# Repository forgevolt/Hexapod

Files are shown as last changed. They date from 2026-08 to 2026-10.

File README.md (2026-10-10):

# Hexapod

A six-legged walking robot built on an ESP32-S3, driving 18 Dynamixel servos with inverse
kinematics at 200 Hz. It walks in three gaits, levels its chassis against uneven ground using
an onboard IMU, and is driven from a separate handheld transmitter over ESP-NOW.

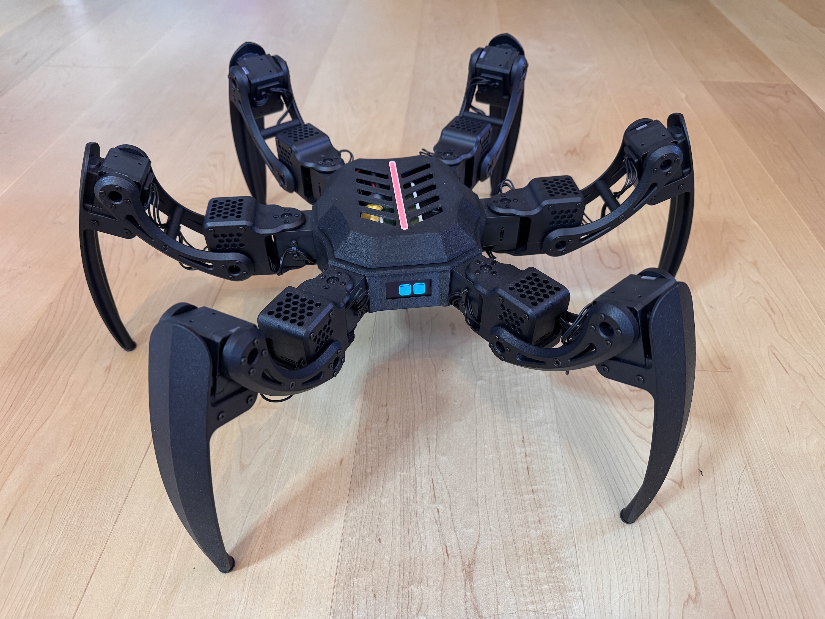
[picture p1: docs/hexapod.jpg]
The hexapod (https://youtu.be/4UdU5Dw7Or8)


▶ **[Watch it walk](https://youtu.be/4UdU5Dw7Or8)** - 14 seconds: leveling on planted feet,
then walking toward the camera.

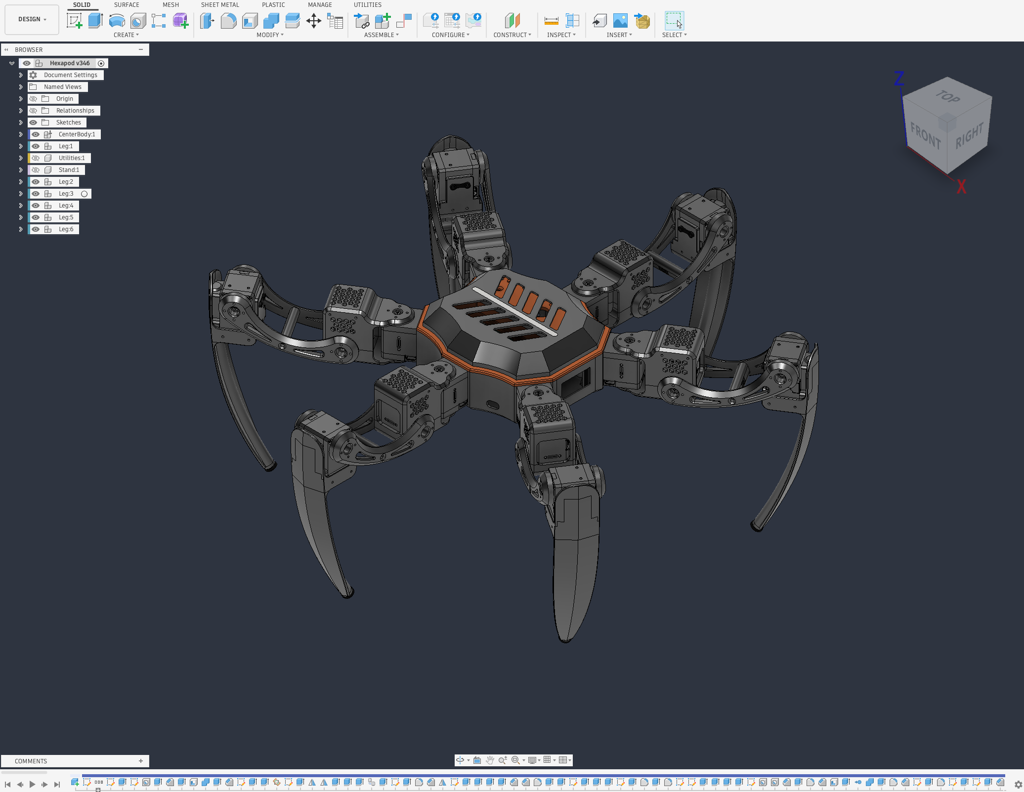
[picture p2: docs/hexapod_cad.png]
The hexapod in Fusion (https://youtu.be/4UdU5Dw7Or8)


## What it does

- **Inverse kinematics per leg.** Each of the six legs solves for coxa, femur and tibia angles
  from a target foot position, with targets clamped to the reachable workspace.
- **Three walking gaits** - tripod, tetrapod and ripple - selected on the fly, with step
  length, step height and ground clearance adjustable from the transmitter while walking.
- **Self-levelling.** `LevelGait` reads the IMU and counters chassis tilt so the body stays
  level on uneven ground while the feet stay planted.
- **Posing.** With the feet planted the chassis can be translated and rotated in roll, pitch
  and yaw, independently of the legs.
- **Animated face.** A 128x64 OLED shows eyes that track the joystick, blink, and change mood
  with the robot's state. It doubles as the fault display when something fails at startup.
- **Sound and lights.** I2S audio for startup, shutdown and error tones, and a 19-LED strip
  whose effect follows the state machine.
- **Power awareness.** Servo torque is released automatically after a period of inactivity,
  and the robot parks itself if the radio link drops.

## Hardware

| Part | What | Notes |
| --- | --- | --- |
| Controller | Custom ESP32-S3 board | 16 MB flash, 8 MB PSRAM; see [`hardware/`](hardware) |
| Servos | 18x Dynamixel XC430-T240BB-T | 3 joints per leg; one half-duplex bus at 3 Mbaud, protocol 2.0 |
| IMU | MPU6050 | I2C, shares the bus with the display |
| Display | SH1106 128x64 OLED | I2C, monochrome |
| LEDs | 19x WS2812B | single data line |
| Audio | I2S DAC / amplifier | 44.1 kHz, 16-bit stereo |
| Transmitter | [Separate handheld unit](https://github.com/forgevolt/Transmitter) | ESP-NOW, WiFi channel 1 |

### Wiring

`software/Hexapod/PinMap.h` is the single source of truth for every GPIO; this table mirrors
it. The schematic is in [`hardware/schematic.pdf`](hardware/schematic.pdf).

| Function | Signal | GPIO |
| --- | --- | --- |
| Dynamixel | RX | 18 |
| Dynamixel | TX | 17 |
| Dynamixel | direction | 16 |
| I2C (display + IMU) | SDA | 8 |
| I2C (display + IMU) | SCL | 9 |
| I2S (audio) | BCLK | 14 |
| I2S (audio) | LRC / word select | 21 |
| I2S (audio) | DOUT | 13 |
| LED strip | data | 11 |
| On/off switch | input | 48 |
| USB sense | input | 10 |

## Repository layout

| | |
|---|---|
| [`software/`](software) | The firmware sketch, plus the bring-up and calibration sketches |
| [`hardware/`](hardware) | PCB: EasyEDA project, Gerbers, schematic, bill of materials |
| [`mechanics/`](mechanics) | Chassis and legs: Fusion source, STLs, dimensioned drawings |
| [`docs/`](docs) | Photographs, the manuals, and the inverse-kinematics write-up |

Each of those has its own README.

### Manuals

| | |
|---|---|
| **[Quick guide](docs/QUICKSTART.md)** | One page, for anyone handed the robot. Controls, what the lights mean, what is normal |
| **[Operating manual](docs/MANUAL.md)** | The full version: servo setup, every control in every mode, timeouts, troubleshooting |

## Getting started

1. Install the required libraries (see **Libraries** below).
2. Open `software/Hexapod/Hexapod.ino` in the Arduino IDE.
3. Select board *ESP32S3 Dev Module* and set the Tools menu as listed under **Board
   settings** below. Four entries differ from the defaults: Flash Size **16 MB**, PSRAM
   **OPI PSRAM** (8 MB), Partition Scheme **Custom** and USB CDC On Boot **Enabled**.
4. Upload.

`software/Hexapod/partitions.csv` sits in the sketch folder, and the ESP32 core picks it up
in preference to the Tools menu: a 6 MB application partition plus a 9.8 MB LittleFS
partition. Nothing in the firmware writes to that filesystem today, but the space is
reserved.

Before the robot will walk, the servos need IDs and a baud rate set, and the joint limits
need to be read off - [`software/DynamixelUtilities/`](software/DynamixelUtilities) exists
for exactly that, and the order to run them in is in that folder's README. One set of limits
covers all six legs (`Hexapod.cpp`), so take values that hold for every leg.

## Building

Built with the **Arduino IDE**, using the **esp32 core 3.3.12** (IDF v5.5.5). It does not
compile against core 2.x.

### Board settings

Board *ESP32S3 Dev Module*, with these Tools-menu settings. The four in bold differ from the
board's defaults.

| Tools menu | Setting |
| --- | --- |
| USB CDC On Boot | **Enabled** |
| CPU Frequency | 240MHz (WiFi) |
| Core Debug Level | None |
| USB DFU On Boot | Disabled |
| Erase All Flash Before Sketch Upload | Disabled |
| Events Run On | Core 1 |
| Flash Mode | QIO 80MHz |
| Flash Size | **16MB (128Mb)** |
| JTAG Adapter | Disabled |
| Arduino Runs On | Core 1 |
| USB Firmware MSC On Boot | Disabled |
| Partition Scheme | **Custom** |
| PSRAM | **OPI PSRAM** |
| Upload Mode | UART0 / Hardware CDC |
| Upload Speed | 921600 |
| USB Mode | Hardware CDC and JTAG |
| Zigbee Mode | Disabled |

For `arduino-cli`, the same settings as an FQBN:

```
esp32:esp32:esp32s3:CDCOnBoot=cdc,FlashSize=16M,PartitionScheme=custom,PSRAM=opi
```

### Libraries

Install through the Arduino library manager. These are the versions it is built and tested
against:

| Library | Version | Note |
| --- | --- | --- |
| FastLED | 3.10.6 | |
| Dynamixel2Arduino | 0.8.2 | |
| MPU6050_light | 1.2.1 | by rfetick - several MPU6050 libraries exist, this is the one used here |
| U8g2 | 2.36.19 | |
| Streaming | 6.3.0 | |
| [SoundEngine](https://github.com/forgevolt/SoundEngine) | 1.1.1 | I2S mixing and the compiled-in clips |
| [ESPNowUtilities](https://github.com/forgevolt/ESPNowUtilities) | 1.0.1 | the ESP-NOW transport `RCProtocol.h` is built on |
| [VectorUtilities](https://github.com/forgevolt/VectorUtilities) | 1.0.0 | `Vector2`/`Vector3`, rotations and the motion curves of the gaits |

The last three are written for this project and its transmitter. All three are in the Arduino
Library Manager, so nothing here needs installing by hand.

`software/Hexapod/RCProtocol.h` defines the wire format, and it is **a copy**: the master
lives in the transmitter repository, because the format follows the transmitter's hardware.
Arduino cannot include across sketch folders, hence the duplication. `cAppProtocolVersion`
is the guard - both ends check it on every frame, so a copy that has fallen behind shows up
as a logged mismatch at pairing rather than as silently misread data.

### Compiler warnings

`software/Hexapod/build_opt.h` switches on more warnings than the core does:

```
-Wall
-Wextra
-Wdouble-promotion
-Wsign-compare
```

`-Wdouble-promotion` matters on the ESP32-S3, which has no hardware double: it catches float
maths that silently turns into slow double maths. `-Wsign-compare` has to be listed by name:
the core's `cpp_flags` passes `-Wno-sign-compare`, and a specific `-Wno-` beats a later
umbrella flag such as `-Wall`. Arduino expands `build_opt.h` after `cpp_flags`, which is why
overriding it there works. Delete the file and these warnings silently disappear from the
build.

The firmware builds without a warning from its own sources. The flags apply to the core and
the libraries as well, so a clean build still lists several hundred warnings from those,
most of them from FastLED.

The IDE setting *Compiler warnings: None* (File → Preferences) passes `-w`, which hides every
warning, including the ones `build_opt.h` asks for. Use *Default* or higher. The IDE's output
panel also drops the start of a long log, so for a full warning check compile with the
`arduino-cli` that ships with the IDE and keep the log in a file outside the repository
(macOS paths):

```bash
CLI="/Applications/Arduino IDE.app/Contents/Resources/app/lib/backend/resources/arduino-cli"
cd software
"$CLI" compile --clean --warnings all \
  --fqbn "esp32:esp32:esp32s3:CDCOnBoot=cdc,FlashSize=16M,PartitionScheme=custom,PSRAM=opi" \
  Hexapod 2>&1 | tee ~/hexapod-build.log
```

`--warnings all` matters: without it `arduino-cli` uses `none`, which passes `-w` just like
the IDE setting. The flags themselves come from `build_opt.h`.

## How it runs

Four FreeRTOS tasks, deliberately split across cores so that nothing can delay servo timing:

| Task | Priority | Core | Rate | Does |
| --- | --- | --- | --- | --- |
| `schedulerTask` | 8 | 1 | 200 Hz | the control loop: gait step, IK, servo write |
| `linkTask` | 3 | 0 | - | ESP-NOW send and receive |
| `peripheralsTask` | 2 | 1 | 50 Hz | IMU read, display and LED updates |
| `fillBuffer` | 1 | 1 | - | mixes and queues the next audio chunk (owned by SoundEngine) |

The display and the IMU share one I2C bus, owned exclusively by `peripheralsTask` - it is the
only task that may touch either. The display runs the bus at 800 kHz and U8g2 does not
restore the previous clock, so the task pulls it back to 400 kHz before every IMU read,
since the MPU6050 is not rated above that.

## Acknowledgements

**Zenta (Kåre Halvorsen)** - the GOAT of hexapods. Years of his work set the bar for what a
legged robot should look like when it moves.
[GitHub](https://github.com/Zenta) · [YouTube](https://www.youtube.com/@ZentaRobotics)

**Design inspiration**

- **Matt Bunting** - [[1]](https://youtu.be/xLxrb_P6N7o) [[2]](https://youtu.be/CVHd2_NUgIs)
- **naoa nya** - [kumokun](https://github.com/naoanya/kumokun/) · [video](https://youtu.be/WcUX7GgypG0)

**Inverse kinematics**

- **Jakob Leander**, *Master Inverse Kinematics for Arduino Robots - Easy Math, Full Code,
  Real Results*. [Video](https://youtu.be/WAsMAeKDc4U) ·
  [Code](https://github.com/JakobLeander/hexapod). The derivation in `Leg.cpp` follows this
  tutorial; [`docs/`](docs) works it through for this geometry.

**Dennis Hoelscher** - [RoboEyes](https://github.com/FluxGarage/RoboEyes), the idea behind
the animated face. `StatusDisplay` was written from a description of the behaviour rather
than from that source; the acknowledgement is in its header.

## Licence

MIT - see [LICENSE](LICENSE). Third-party library licences are listed in
[THIRD_PARTY.md](THIRD_PARTY.md).

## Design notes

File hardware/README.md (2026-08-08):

# PCB

The custom ESP32-S3 controller board: everything needed to have it made, and to change it.

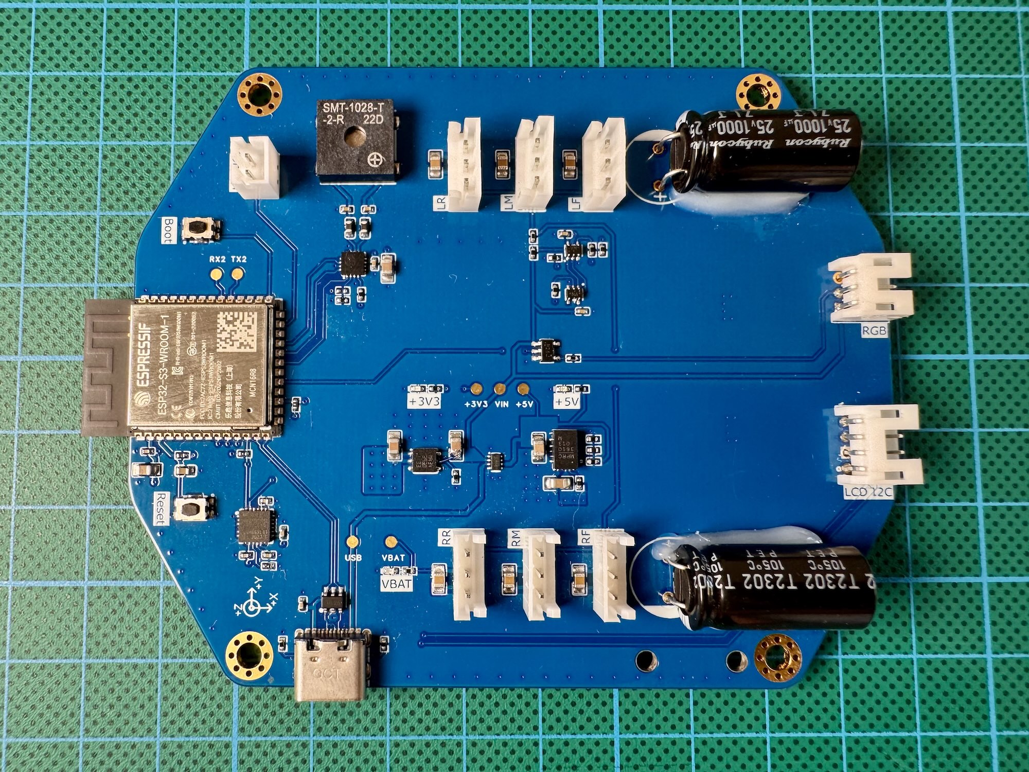
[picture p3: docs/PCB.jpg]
PCB


| Test harness 1 | Test harness 2 |
|---|---|
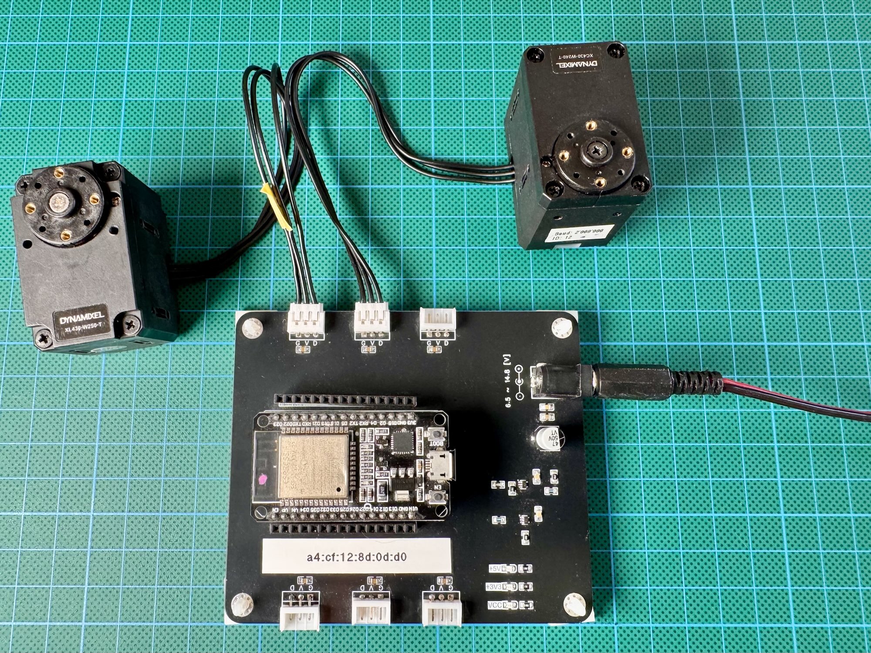
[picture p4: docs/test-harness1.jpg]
Test 1
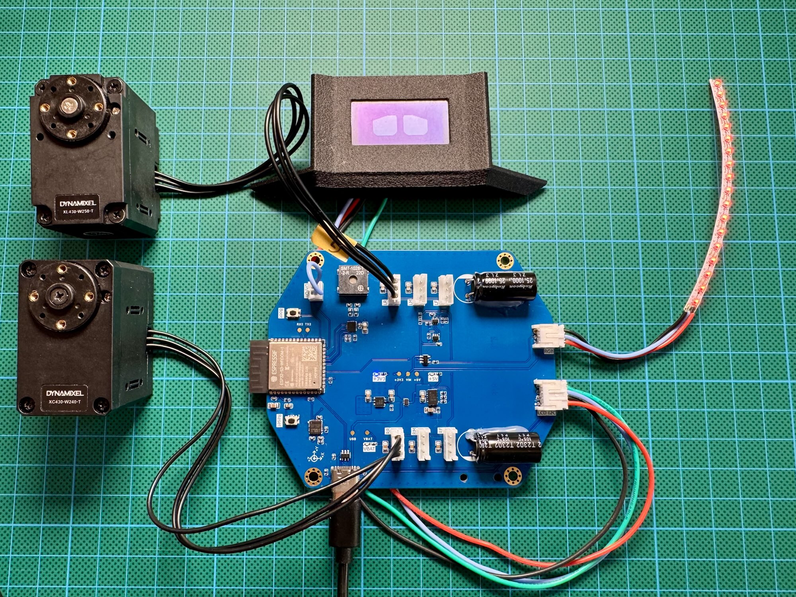
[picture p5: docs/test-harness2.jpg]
Test 2
|  |  |

| Path | Contents |
|---|---|
| `easyeda/ProPrj_Hexapod_2026-08-06.epro2` | The editable EasyEDA Pro project - schematic and layout |
| `gerber/Gerber_HexapodPCB_R2_2026-08-06.zip` | Fabrication files for revision R2, zipped as a fab expects them |
| `schematic.pdf` | The schematic as a document, readable without EasyEDA |
| `bom.csv` | Bill of materials, with LCSC part numbers |
| `MPM3610Calculator.xlsx` | Working sheet for the MPM3610 buck regulator - feedback divider and inductor choice |

The board here is **revision R2**. The Gerber archive and the EasyEDA project carry the
revision and the export date in their filenames, so a later revision can sit beside this one
rather than silently replacing it.

## Ordering a board

Upload `gerber/Gerber_HexapodPCB_R2_2026-08-06.zip` as it is - a standard Gerber and drill
set. The BOM lists LCSC part numbers, which suits JLCPCB assembly, but nothing in the design
depends on a particular fab.

If you revise the layout, tag this repository when you order from it. A year later, "which
files made the board in my hand" then has an answer the tree alone cannot give.

## The BOM

`bom.csv` is exported from EasyEDA and is UTF-8. Some manufacturer names carry their Chinese
form alongside the Latin one - `SAMSUNG(三星)`, `KELIKING(凯丽金)` - which is how LCSC lists
them. If those render as mojibake, the reader is guessing the encoding rather than the file
being wrong.

## What is on the board

From the BOM, the parts worth naming:

| Part | Function |
|---|---|
| MPM3610GQV-Z | Step-down module, the +5V rail |
| LD39200PUR | 2 A LDO, the +3V3 rail |
| SMCJ15A | TVS on the battery input |
| 74LVC1G125 / 74LVC1G126 | The direction buffers that make the Dynamixel bus half-duplex |
| MAX98357AETE+T | I2S class-D amplifier |
| MPU-6050 | IMU |

`MPM3610Calculator.xlsx` is the working sheet behind the buck regulator's component values.
The schematic is the authority for what was actually built.

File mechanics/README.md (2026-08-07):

# Mechanics

The chassis and legs: Fusion source, print-ready meshes, and the dimensioned drawings.

| Path | Contents |
|---|---|
| `cad/Hexapod.f3z` | The Fusion source, as an archive containing the whole assembly |
| `stl/` | Print-ready meshes, 18 parts |
| `dimensions-top.png`, `dimensions-side.png` | Overall dimensions |

## Leg naming

The code names each leg's three links after an insect's, and the STLs follow:

| Link | Joint it rotates about | Moves |
|---|---|---|
| **Coxa** | vertical, at the body | the leg left and right, swinging it around the chassis |
| **Femur** | horizontal, at the coxa | the leg up and down |
| **Tibia** | horizontal, at the femur's far end | the foot in and out, setting how far the leg reaches |

`Leg.cpp` solves for the three angles in that order, and `PresentPosition/` prints them in
it too.

## The parts

| Group | Parts | Per robot |
|---|---|---|
| Centre body | `CenterBody-Main`, `-TopPlate`, `-CoverWithDiffusor`, `-CoverLedHolder`, `-ConnectorTopPlate`, `-ConnectorCover`, `-DisplayHolderLeft`, `-DisplayHolderRight` | 1 each |
| Cable entries | `CenterBody-Grommet-1Cable`, `-Grommet-2Cable`, `Femur-Groomet`, `CoxaTibia-CableFixture` | as needed |
| Leg | `Coxa-Upper`, `Coxa-Lower`, `Femur-Bracket1`, `Femur-Bracket2`, `Femur-ConnectingBracket`, `Tibia` | 6 each |

Six legs means the leg parts print six times over. Mirroring is not required - the legs are
identical and their difference is in the firmware's per-leg mounting angles.

## Opening the CAD

`Hexapod.f3z` is a Fusion archive rather than a single `.f3d` part - open it with
*File → Open* in Fusion, which unpacks the design and its components.

There is no STEP export here. If you want to modify the chassis without a Fusion licence, a
STEP export is the thing to ask for; the STLs are fine for printing but carry no editable
geometry.

## Printing

No slicer projects are included, so use your own profile. The parts that carry load are the
coxa and femur brackets and the centre body's top plate - a leg's own weight plus the
servo's stall torque goes through them, so treat infill and wall count there as structural
rather than cosmetic. The cover with the diffusor is the exception in the other direction:
it is meant to pass light from the LED strip.

## Servo and bracket geometry

The printed parts are dimensioned around two ROBOTIS components:

| Part | Role |
|---|---|
| **XC430-T240BB-T** | the servo, three per leg |
| **HN11-I101** | the idler bearing set for DYNAMIXEL XL 430 series |

Their drawings and STEP models are not reproduced here - they are ROBOTIS's documents, and
the current versions are on the
[ROBOTIS e-Manual](https://docs.robotis.com/docs/dxl/model_reference/x_series/xc_series/xc430-t240bb). Download them
from there if you need to check a fit or modify a bracket.

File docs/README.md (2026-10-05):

# Documentation

| Path | Contents |
|---|---|
| [`QUICKSTART.md`](QUICKSTART.md) | Quick guide - one page, for anyone handed the robot |
| [`MANUAL.md`](MANUAL.md) | Operating manual - servo setup, every control, troubleshooting |
| `state-machine-detail.md` | The state machine with guards, gaits and constants from `Hexapod.cpp` |
| `state-machine.svg`, `state-machine-detail.svg` | The same two diagrams as SVG, if you prefer them to the inline Mermaid |
| `transmitter-controls.jpg` | The annotated transmitter photo the quick guide shows |
| `hexapod.jpg` | The photograph the top-level README shows |
| `PCB.jpg` | The assembled controller board, shown in `hardware/README.md` |
| `test-harness1.jpg`, `test-harness2.jpg` | The bring-up harness, shown in `hardware/README.md` |
| `Hexapod-IKMath.pdf` | The inverse-kinematics derivation for this geometry |

## `Hexapod-IKMath.pdf`

The maths behind `software/Hexapod/Leg.cpp`, worked through for this robot's link lengths
and mounting angles: from a target foot position in body coordinates, to coxa, femur and
tibia angles.

`Leg.cpp` follows the approach in Jakob Leander's
[tutorial](https://youtu.be/WAsMAeKDc4U); this document carries it through for the
dimensions in `mechanics/`, which is what makes the constants in the code readable rather
than magic.

`software/IKMath/` is the runnable companion - the same `Leg` code, with no
robot attached.

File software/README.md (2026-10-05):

# Software

Four sketch trees. Only the first one is the robot; the rest are bring-up tools that exist
because an 18-servo machine is painful to debug all at once.

| Path | What |
|---|---|
| `Hexapod/` | The firmware. This is the one you flash |
| `DynamixelUtilities/` | Servo setup and measurement, run before first assembly |
| `IKMath/` | The inverse kinematics on its own, no robot required |
| `HWTests/` | Per-peripheral smoke tests |

## `Hexapod/` - the firmware

| Files | Responsibility |
| --- | --- |
| `Hexapod.ino`, `Hexapod.*` | state machine, task setup, telemetry, and the top-level `step()` |
| `Leg.*` | per-leg inverse and forward kinematics (the vector maths come from VectorUtilities) |
| `GaitEngine.*`, `Gaits.*` | gait scheduling, and the park, stand, pose, level and walking gaits |
| `ServoBus.*` | the Dynamixel bus: sync read/write, joint limits, torque |
| `Receiver.*`, `RCProtocol.h` | the ESP-NOW link, control data in and telemetry out |
| `StatusDisplay.*` | the eyes and the fault display |
| `IndicatorLeds.*` | the LED strip effects |
| `PinMap.h` | every GPIO in the project |
| `build_opt.h` | extra compiler warnings: `-Wall -Wextra -Wdouble-promotion -Wsign-compare` |
| `partitions.csv` | 6 MB app + 9.8 MB LittleFS; overrides the Tools menu |

The state machine in `Hexapod.cpp` - every state, guard, gait and timeout - is drawn in
[`docs/state-machine-detail.md`](../docs/state-machine-detail.md).

Audio and radio transport are not here - they are the `SoundEngine` and `ESPNowUtilities`
libraries, installed through the Library Manager. `RCProtocol.h` is a copy of the
transmitter's master; see the note in the top-level README.

## `DynamixelUtilities/` - servo setup

Each sketch talks to the servo bus and nothing else. Out of the box a Dynamixel is ID 1 at
57600 baud, so a new leg has to be set up one servo at a time, with only that servo on the
bus.

Run them roughly in this order when building a leg:

| Sketch | What it does |
|---|---|
| `SetBaudRate/` | Scans the bus, detects the current baud rate, sets it to the target. One servo at a time |
| `SetID/` | Same scan, then assigns the servo its ID. One servo at a time |
| `DefaultPosition/` | Drives every servo on the bus to 2048, the mechanical centre. Assemble the joint in this position |
| `PresentPosition/` | Prints the live positions of one leg's three servos, and the min/max seen. This is how the joint limits in `ServoBus` were measured |
| `Position1/`, `Position2/` | Two approaches to smooth point-to-point motion: way points with a blend threshold, versus streaming goal positions at 100-200 Hz. The firmware uses the second |

**Set the baud rate and the ID with one servo connected.** Both sketches scan and write to
whatever they find, so a whole bus will end up with the same ID.

## `IKMath/` - kinematics without the robot

`IKMath.ino` runs the same `Leg` as the firmware, decoupled from the
state machine, the radio and the gaits. It made the maths debuggable in isolation, and it is
the sketch to reach for when changing the kinematics. `Leg.*` and `ServoBus.*` here
are copies of the firmware's, for the same Arduino include reason as `RCProtocol.h` - keep
them in step.

## `HWTests/`

| Sketch | Needs | Checks |
|---|---|---|
| `StatusDisplayTest/` | an SH1106 OLED on I2C | Walks the whole `StatusDisplay` API - eyes, moods, blinking, the fault face - holding each step long enough to watch and logging what it is showing |
| `tone/` | the I2S amplifier | Plays C5-E5-G5. Enough to tell wiring from software |

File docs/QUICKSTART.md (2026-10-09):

# Quick guide

How to drive the hexapod. No prior knowledge needed.

## Switch it on

Turn on the transmitter, then the robot. The robot plays a sound, folds its legs into a
resting crouch, and pulses red while it looks for the transmitter. That takes a few seconds.

When the eyes open and the transmitter shows the robot's name, it is ready.

**Press the left button** to make it stand up.

## The controls

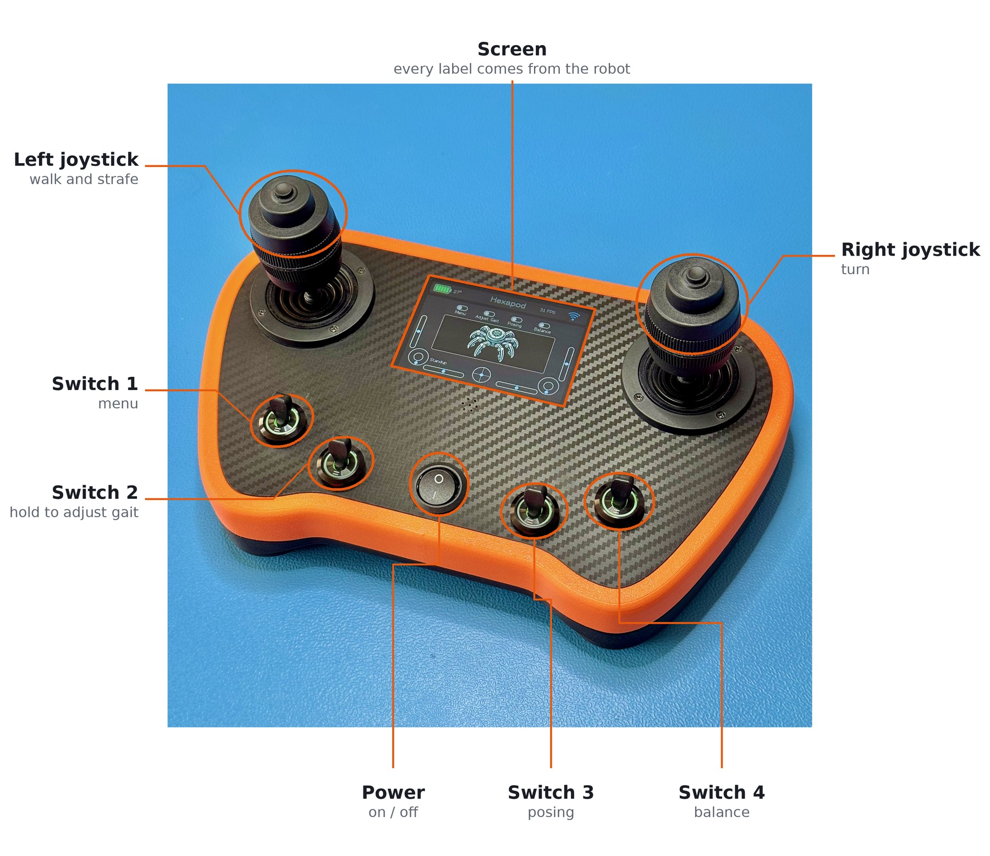
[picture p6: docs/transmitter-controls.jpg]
The transmitter's controls


*The two-joystick transmitter. The one-joystick version has the same switches, and you turn
by twisting the single stick.*

The transmitter labels every switch and button, and those labels change with what the robot
can do right now. A blank label means that control does nothing at the moment.

| Control | Does |
|---|---|
| **Left button** | Stand up, or lie back down |
| **Right button** | Change the walking style. While it lies down: set what counts as level (see below) |
| **Switch 2** — *Adjust Gait* | Hold to change how it walks (see below) |
| **Switch 3** — *Posing* | Feet stay put, the body moves |
| **Switch 4** — *Balance* | The robot keeps itself level |

## Walking

Once it is standing, **just push the left stick**. There is no separate "go" command.

- **Forward and back**, **left and right**: the left stick
- **Turning**: the right stick sideways, or — if your transmitter has only one stick —
  twist that stick

**How far you push decides how fast it walks.** Push gently for a slow walk. Let go and it
finishes its step and stops.

The **right button** cycles through three walking styles while it walks:

- **Tripod** — quick, moves three legs at once
- **Tetrapod** — a good all-rounder
- **Ripple** — slow and steady, one leg at a time, best on rough ground

## Changing how it walks

**Hold Switch 2** and the right stick stops steering and starts adjusting instead:

- **Sideways** — how big a stride it takes
- **Up and down** — how high it stands
- **Twist** — how high it picks its feet up

The values show on the transmitter as you change them, and they stay where you leave them.
It walks straight while you are holding Switch 2 — you cannot steer and adjust at once.

Without Switch 2 held, pushing the right stick up and down still raises and lowers the body,
but only for as long as you hold it. Useful for ducking under something.

## Posing and balancing

**Switch 3 — Posing.** The feet stay planted and the body moves on top of them. The left
stick shifts it around and up and down; the right stick tilts and turns it. Movements are
deliberately soft and slow.

*A trick:* with Switch 3 and Switch 4 both on, tilt the **transmitter itself** and the robot's
body copies you.

**Switch 4 — Balance.** The robot feels which way is down and keeps its body level, even if
the ground is not. Stand it on a slope and it will straighten up. It does not walk while
doing this.

If it holds itself a little crooked on flat ground, let it lie down on a level floor and press
the **right button** (*Level IMU*). A short signal confirms it, and it remembers this from then
on. This needs the two-joystick transmitter.

Turn the switch off and it goes back to standing normally.

## What it is telling you

**The lights:**

| | |
|---|---|
| Pulsing red | Standing by, not moving |
| Pulsing orange | Posing or balancing |
| Running along the body | Walking — the direction follows where it is going |

**The eyes:** tired while starting up, curious while standing, narrowed and focused while
walking, happy while posing or balancing. They follow the stick as you steer.

## Things that are normal

**It goes limp after a while.** If it sits parked and unused for a minute, it relaxes its
joints so the motors do not overheat. Any command wakes it up again.

**It lies down on its own.** Left standing with nothing to do for half a minute, it parks
itself.

**It parks when you switch the transmitter off** — or when you walk out of range. It stands
by and re-connects on its own as soon as the transmitter is back.

**Buttons go blank for a few seconds.** It is standing up or lying down, and will not take
new commands until it has finished.

## If something is wrong

The robot shows faults on its own screen, as a crossed-eye face with a line of text, along
with a warning sound.

| It says | Meaning |
|---|---|
| **SERVO INIT FAILED** | The legs did not respond at startup. Switch it off and check that servo power is connected. **Do not ask it to stand.** |
| **ABNORMAL RESET** | The last run ended badly rather than being switched off. It clears itself after twenty seconds. If it says *brownout*, the battery is probably low |
| **IMU INIT FAILED** | The balance sensor did not respond at startup. Everything else works, but Balance will not level the robot. This one comes without the warning sound |
| **SERVO READ FAILED** | The robot could not tell where its legs are. If its legs were limp, it leaves them limp instead of moving them blindly and tries again with the next park or stand-up; if it was standing, a leg may have lost its connection. If it keeps happening, switch off and check the servo cables. This one comes without the warning sound |
| **BATTERY LOW** | The battery is nearly empty. The message and the sound come back every minute until you park the robot and change or charge the battery |

**Nothing responds and it keeps pulsing red.** It has not found the transmitter. Check the
transmitter is on and paired.

**It walks but will not turn.** Switch 2 is on — steering is off while you are adjusting.

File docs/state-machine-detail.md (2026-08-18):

# State machine — firmware view

Every state, guard, gait and timeout in `software/Hexapod/Hexapod.cpp`. For the same machine
in operating terms, see [the manual](MANUAL.md#the-five-things-it-does).

The Mermaid below is the source. [`state-machine-detail.svg`](state-machine-detail.svg) is the
same diagram exported for printing - **if you change one, change the other.**

```mermaid
flowchart LR
    Off["eOff"] -->|"isSwitchOn()<br>play(startupClip)<br>ParkGait 3000 ms"| Init["eInitializing"]
    Init -->|"!isSwitchOn()<br>setTorqueOff()<br>play(shutdownClip)"| Off
    Init -->|"isLinkHealthy()<br>re-park if !isAllTorqueOn()"| Ready["eReady"]
    Init -->|"60 s: setTorqueOff()"| Init
    Ready -->|"60 s: setTorqueOff()"| Ready
    Ready -->|"joyL &amp;&amp; canChangeGait()<br>StandUpGait 3000 ms"| Standing["eStanding"]
    Standing -->|"30 s idle<br>ParkGait 3000 ms"| Ready
    Standing -->|"any axis != 0 ||<br>joyR || switch2<br>walkingGaits[i]"| Walking["eWalking"]
    Walking -->|"15 s idle &amp;&amp; !switch2<br>StandUpGait 1000 ms"| Standing
    Walking -->|"joyR: ++gait index"| Walking
    Standing -->|"switch3<br>PosingGait"| Posing["ePosing"]
    Posing -->|"!switch3<br>StandUpGait 1000 ms"| Standing
    Standing -->|"switch4<br>LevelGait"| Leveled["eStandingLeveled"]
    Leveled -->|"!switch4<br>StandUpGait 1000 ms"| Standing
    Walking -.->|"switch3 &amp;&amp; !switch2<br>PosingGait"| Posing
    Walking -.->|"switch4 &amp;&amp; !switch2<br>LevelGait"| Leveled
    Leveled -.->|"switch3<br>PosingGait"| Posing

    N["<b>Common to the four active states</b><br>eStanding, eWalking, ePosing, eStandingLeveled<br>&nbsp;<br>joyL → ParkGait 3000 ms → eReady<br>!isLinkHealthy() || !isSwitchOn()<br>&nbsp;&nbsp;→ handleConnectionLoss(true) → eInitializing<br>&nbsp;&nbsp;the same from eReady, but with (false):<br>&nbsp;&nbsp;no gait is running there to interrupt"]
    Off ~~~ N

    linkStyle 14,15,16 stroke:#3A56A8,color:#3A56A8
    classDef s_off  fill:#E7E9EC,stroke:#3A4048,stroke-width:2px,color:#1A1E24
    classDef s_init fill:#FDE7D6,stroke:#E8590C,stroke-width:2px,color:#1A1E24
    classDef s_stnd fill:#FFF3BF,stroke:#B58B00,stroke-width:2px,color:#1A1E24
    classDef s_walk fill:#D9F2E0,stroke:#2B8A3E,stroke-width:2px,color:#1A1E24
    classDef s_mode fill:#E3E9FB,stroke:#3A56A8,stroke-width:2px,color:#1A1E24
    classDef s_note fill:#FFFDF3,stroke:#B58B00,stroke-width:1.5px,color:#1A1E24
    class Off s_off
    class Init,Ready s_init
    class Standing s_stnd
    class Walking s_walk
    class Posing,Leveled s_mode
    class N s_note
```

## Guards

`isLinkHealthy()` = `isPaired()` **and** `timeSinceLastControlData()` ≤ 250 ms. The two are
deliberately independent: the first is the transport layer's opinion, the second is the
control loop's own, and it catches a stalled WiFi task that would never clear the peer.

`canChangeGait()` gates every handler **except** `stepWalking()`. A state change from walking
therefore takes effect immediately while the gait switch is deferred to the end of the cycle;
the destination handler's own entry gate covers the gap.

## Constants

All in `Hexapod.cpp`.

| | |
|---|---|
| `cParkDurationMs` | 3000 |
| `cStandUpFromParkedMs` | 3000 |
| `cStandUpDeployedMs` | 1000 |
| `cIdleTimeout` | 15000 |
| `cWaitTimeUntilTorqueOff` | 60000 |
| `cControlDataTimeoutMs` | 250 |

## Regenerating the SVGs

Both SVGs are built with graphviz from the sources in [`diagrams/`](diagrams), then composed
so the note sits below the graph - `dot` lays nodes out by rank and cannot place a note
underneath a left-to-right graph on its own.

```
cd docs/diagrams
./build.sh          # needs graphviz and python3
```

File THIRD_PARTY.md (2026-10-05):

# Third-party licences

This firmware is MIT licensed (see LICENSE). It builds against the libraries below. None of
them are redistributed here - each is installed through the Arduino library manager and
keeps its own licence.

| Library | Licence | Used for |
| --- | --- | --- |
| FastLED | MIT | the indicator LED strip |
| MPU6050_light | MIT | the onboard IMU |
| Dynamixel2Arduino | Apache-2.0 | the servo bus |
| U8g2 | BSD 2-clause (code)  | the OLED display |
| Streaming | LGPL-2.1-or-later | the `Serial <<` logging |
| SoundEngine | MIT | I2S mixing and playback |
| ESPNowUtilities | MIT | the ESP-NOW link to the transmitter |
| VectorUtilities | MIT (raymath: zlib)  | vectors, rotations, motion curves |

The last three are written for this project and published separately, under the same MIT
licence as this repository:
[SoundEngine](https://github.com/forgevolt/SoundEngine),
[ESPNowUtilities](https://github.com/forgevolt/ESPNowUtilities) and
[VectorUtilities](https://github.com/forgevolt/VectorUtilities). VectorUtilities' vector code is
derived from raymath, part of [raylib](https://github.com/raysan5/raylib) (zlib licence); the
library carries raylib's licence notice.

## Streaming

`Streaming.h` by Mikal Hart is used for logging throughout the firmware. The LGPL does not
affect the licence of this project, but it asks that anyone who receives a binary can relink
it against a modified version of the library. Complete source is published here and no
pre-built binaries are distributed, so a recipient can modify Streaming and rebuild.

## U8g2 fonts

U8g2's code is BSD 2-clause, but its fonts are licensed separately. StatusDisplay renders
fault text with `u8g2_font_helvR08_tr`, derived from HELVR08.BDF:

    Copyright 1984-1989, 1994 Adobe Systems Incorporated.
    Copyright 1988, 1994 Digital Equipment Corporation.

    Permission to use, copy, modify, distribute and sell this software and its
    documentation for any purpose and without fee is hereby granted, provided that
    the above copyright notices appear in all copies. Adobe Systems and Digital
    Equipment Corporation make no representations about the suitability of this
    software for any purpose. It is provided "as is" without express or implied
    warranty.

The same notice is reproduced at the top of `StatusDisplay.h`.

## StatusDisplay

Written for this project, implemented from a description of the behaviour rather than from
the source of FluxGarage RoboEyes, which inspired it. The acknowledgement is in the header.

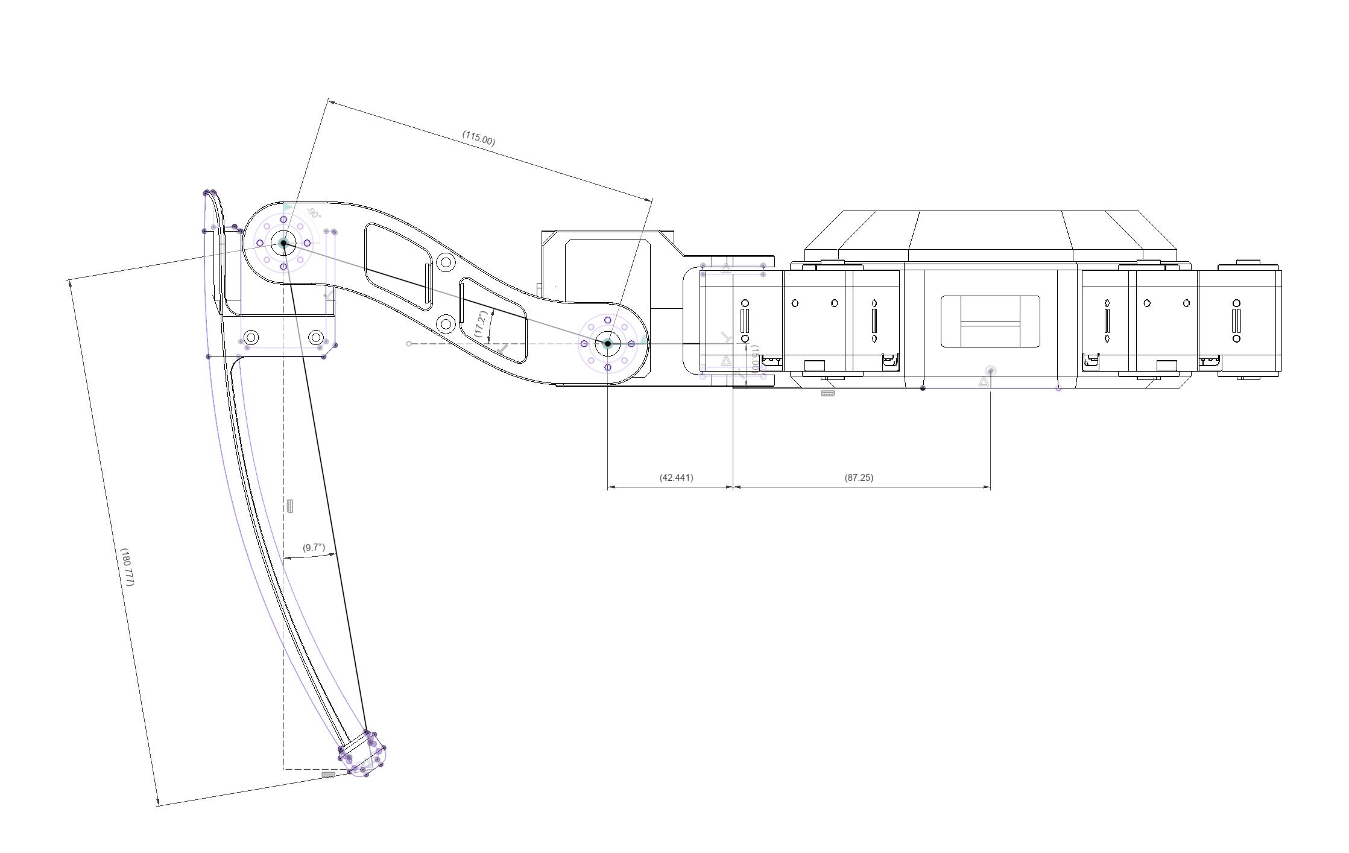
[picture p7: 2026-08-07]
mechanics/dimensions-side.png

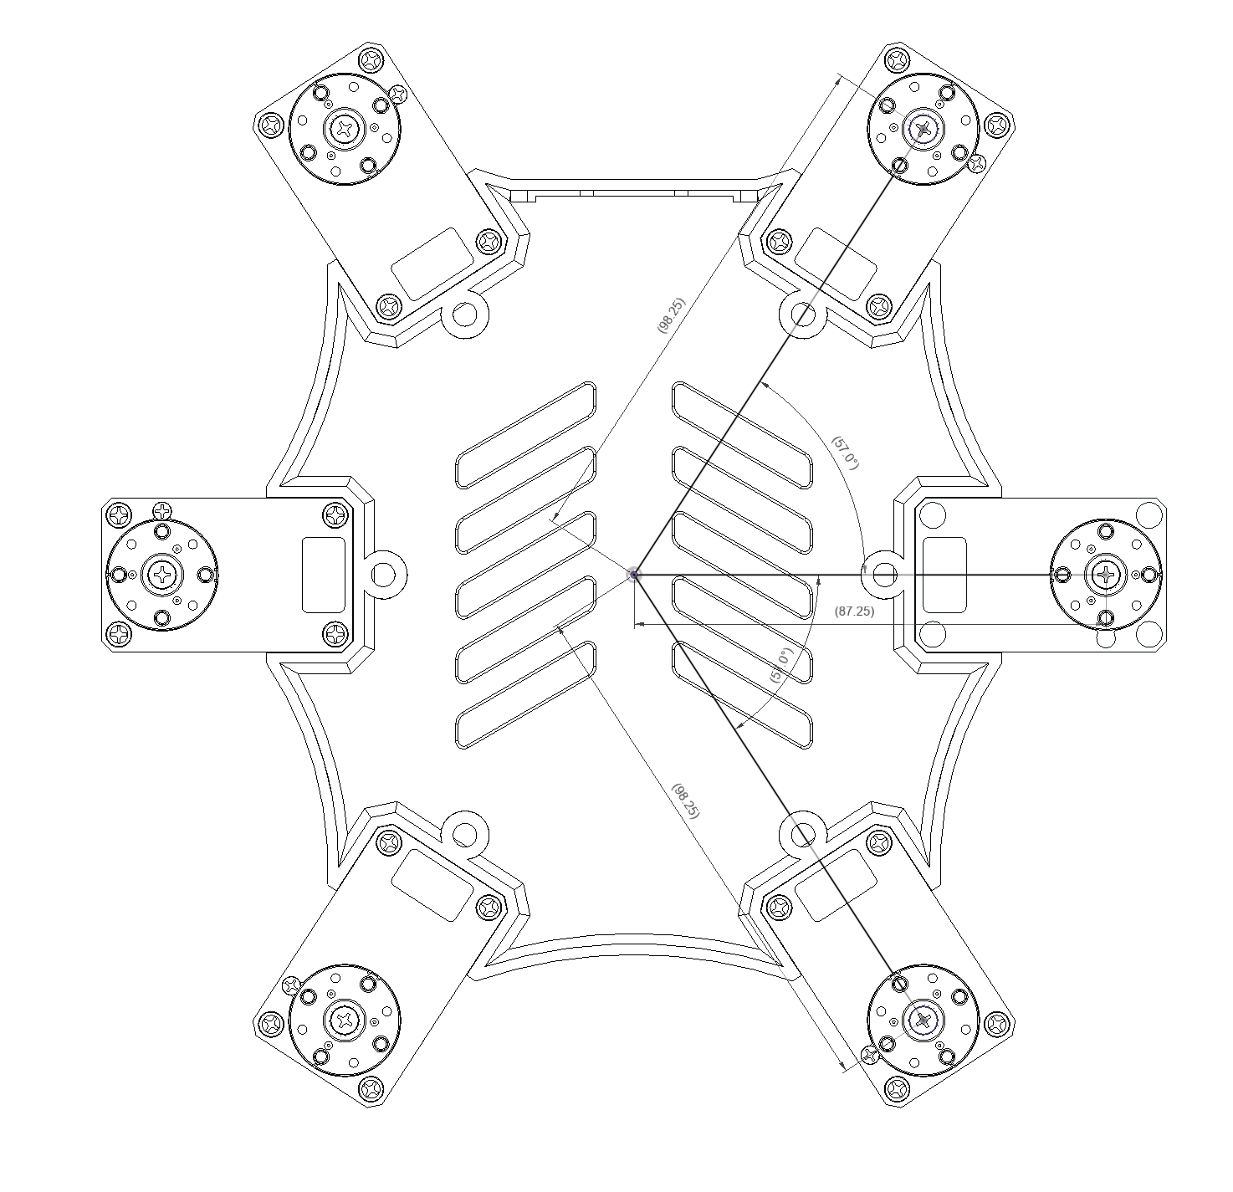
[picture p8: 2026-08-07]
mechanics/dimensions-top.png

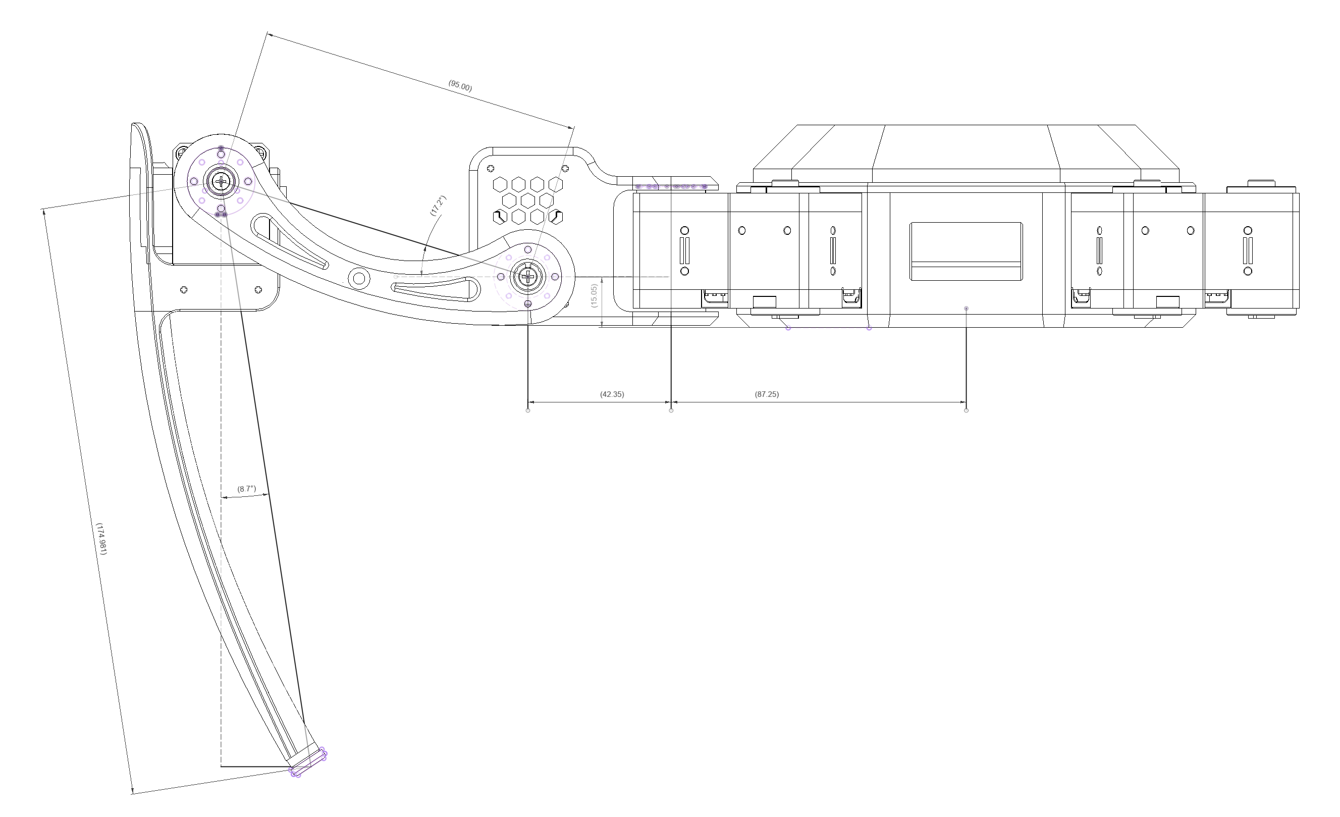
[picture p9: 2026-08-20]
docs/side_distances_for_IK.png

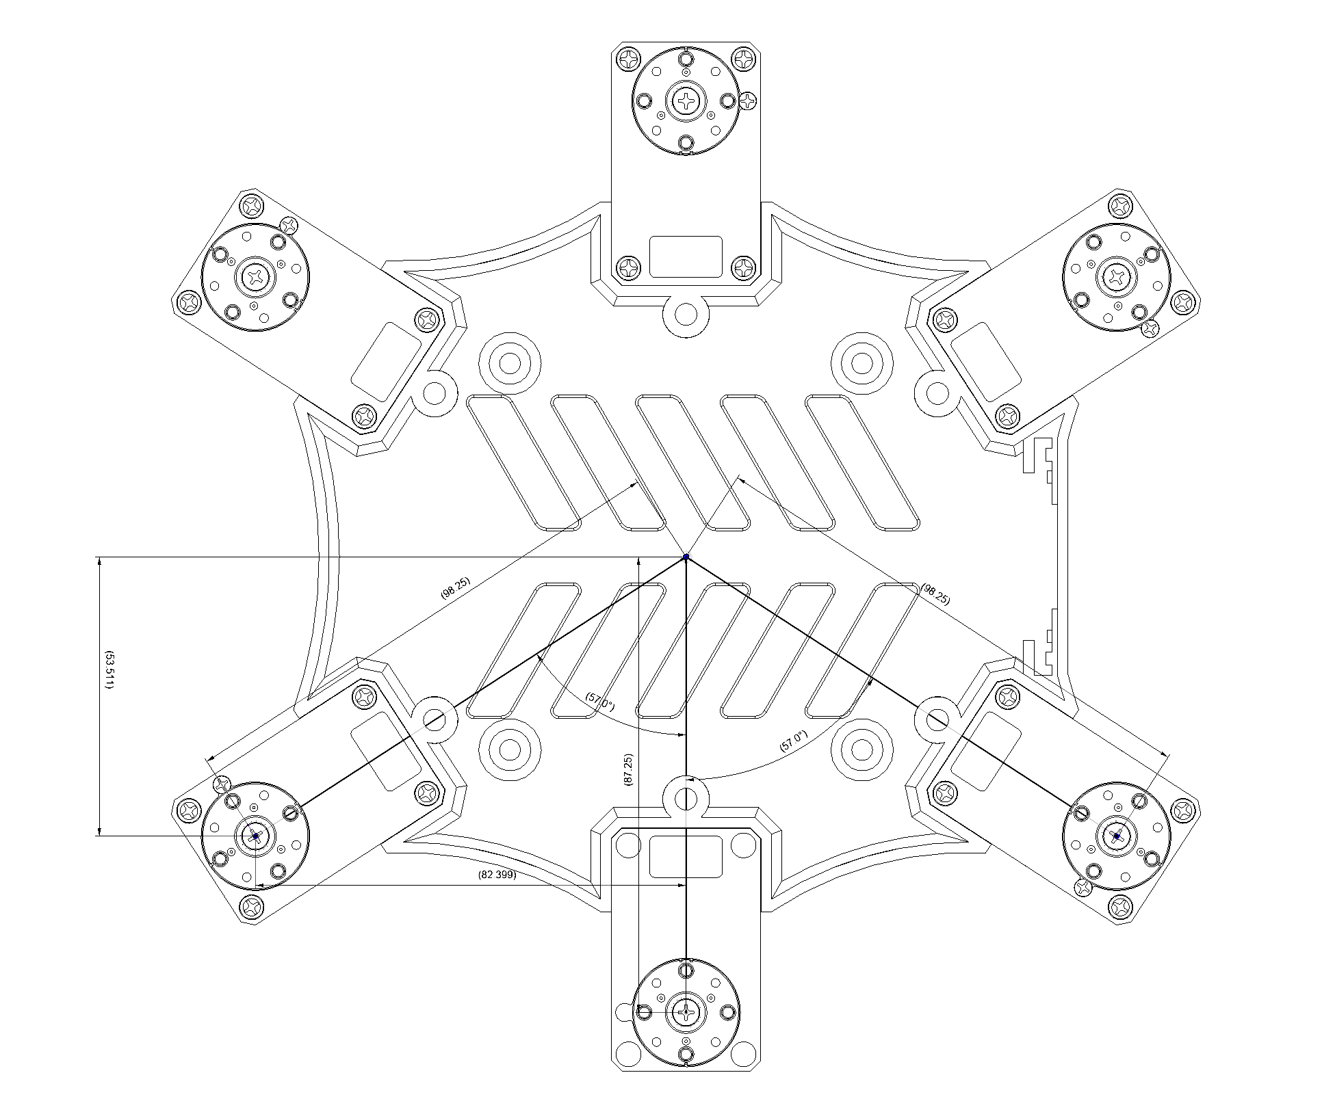
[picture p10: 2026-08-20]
docs/top_distances_for_IK.png

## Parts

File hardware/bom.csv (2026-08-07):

No. | Quantity | Comment | Designator | Footprint | Value | Manufacturer Part | Manufacturer | Supplier Part | Supplier
1 | 1 | BatteryPads | B400 | BatteryPads
2 | 7 | 100nF | C200,C302,C501,C601,C602,C802,C805 | C0402_IPC | 100nF | CL05B104KO5NNNC | SAMSUNG(三星) | C1525 | LCSC
3 | 1 | 1uF | C300 | C0603 | 1uF | CL10B105KP8NNNC | SAMSUNG(三星) | C95843 | LCSC
4 | 2 | 22uF | C301,C404 | C0805 | 22uF | CL21A226MAQNNNE | SAMSUNG(三星) | C45783 | LCSC
5 | 2 | 1000uF | C400,C401 | CAP-TH_BD10.0-P5.00-D1.0-FD | 1000uF | 25YXJ1000M10X20 | rubycon(红宝石) | C88720 | LCSC
6 | 7 | 100nF | C402,C800,C801,C803,C804,C806,C807 | C0805 | 100nF
7 | 1 | 1uF | C403 | C0805 | 1uF | CL21B105KBFNNNE | SAMSUNG(三星) | C28323 | LCSC
8 | 4 | 10uF | C405,C406,C407,C500 | C0805 | 10uF | GCM21BR71A106KE22L | muRata(村田) | C126586 | LCSC
9 | 2 | 220pF | C502,C503 | C0402_IPC | 220pF | 0402B221K500NT | FH(风华) | C1530 | LCSC
10 | 1 | 10nF | C600 | C0402_IPC | 10nF | GRM155R71E103KA01D | muRata(村田) | C77013 | LCSC
11 | 1 | 2.2nF | C603 | C0402_IPC | 2.2nF | 0402B222K500NT | FH(风华) | C1531 | LCSC
12 | 1 | On/Off | CN700 | CONN-TH_B2B-PH-K-S |  | B2B-PH-K-S(LF)(SN) | JST | C131337 | LCSC
13 | 1 | LF | CN800 | CONN-TH_B3B-EH-A-LF-SN |  | B3B-EH-A(LF)(SN) | JST | C160259 | LCSC
14 | 1 | RF | CN801 | CONN-TH_B3B-EH-A-LF-SN |  | B3B-EH-A(LF)(SN) | JST | C160259 | LCSC
15 | 1 | LM | CN802 | CONN-TH_B3B-EH-A-LF-SN |  | B3B-EH-A(LF)(SN) | JST | C160259 | LCSC
16 | 1 | RM | CN803 | CONN-TH_B3B-EH-A-LF-SN |  | B3B-EH-A(LF)(SN) | JST | C160259 | LCSC
17 | 1 | LR | CN804 | CONN-TH_B3B-EH-A-LF-SN |  | B3B-EH-A(LF)(SN) | JST | C160259 | LCSC
18 | 1 | RR | CN805 | CONN-TH_B3B-EH-A-LF-SN |  | B3B-EH-A(LF)(SN) | JST | C160259 | LCSC
19 | 1 | USBLC6-2SC6 | D200 | SOT-23-6_L2.9-W1.6-P0.95-LS2.8-BL |  | USBLC6-2SC6 | ST(意法半导体) | C7519 | LCSC
20 | 1 | SMCJ15A | D400 | SMC_L6.9-W5.9-LS7.9-RD |  | SMCJ15A | Littelfuse(美国力特) | C1973072 | LCSC
21 | 2 | GZ1608D121TF SMT业务专用 | L500,L501 | L0603 |  | GZ1608D121TF SMT业务专用 |  | C18527 | LCSC
22 | 1 | VBAT | LED400 | LED0402-RD_YELLOW
23 | 1 | +5V | LED401 | LED0402-RD_YELLOW
24 | 1 | +3V3 | LED402 | LED0402-RD_YELLOW
25 | 4 | M3-MOUNT-HOLE | M700,M701,M702,M703 | M3-MOUNT-HOLE
26 | 2 | 5.1kΩ | R200,R201 | R0402 | 5.1kΩ | 0402WGF5101TCE | UNI-ROYAL(厚声) | C25905 | LCSC
27 | 6 | 10kΩ | R300,R400,R401,R800,R801,R805 | R0402 | 10kΩ | 0402WGF1002TCE | UNI-ROYAL(厚声) | C25744 | LCSC
28 | 4 | 4.7kΩ | R301,R302,R402,R600 | R0402 | 4.7kΩ | 0402WGJ0472TCE | UNI-ROYAL(厚声) | C25940 | LCSC
29 | 3 | 100kΩ | R403,R410,R411 | R0402 | 100kΩ | 0402WGF1003TCE | UNI-ROYAL(厚声) | C25741 | LCSC
30 | 1 | 120kΩ | R404 | R0402 | 120kΩ | RC0402FR-07120KL | YAGEO(国巨) | C93945 | LCSC
31 | 1 | 22kΩ | R405 | R0402 | 22kΩ | RT0402BRD0722KL | YAGEO(国巨) | C326601 | LCSC
32 | 1 | 0Ω_DNP | R500 | R0402 | 0Ω | 0402WGJ0000TCE | UNI-ROYAL(厚声) | C21376 | LCSC
33 | 1 | 0Ω | R501 | R0402 | 0Ω | 0402WGJ0000TCE | UNI-ROYAL(厚声) | C21376 | LCSC
34 | 1 | 1MΩ | R502 | R0402 | 1MΩ | 0402WGF1004TCE | UNI-ROYAL(厚声) | C26083 | LCSC
35 | 1 | 470Ω | R700 | R0402 | 470Ω | 0402WGF4700TCE | UNI-ROYAL(厚声) | C25117 | LCSC
36 | 1 | 470Ω | R802 | R0402 | 470Ω | RC0402FR-07470RL | YAGEO(国巨) | C114877 | LCSC
37 | 2 | 220Ω | R803,R804 | R0402 | 220Ω | 0402WGF2200TCE | UNI-ROYAL(厚声) | C25091 | LCSC
38 | 1 | Boot | SW300 | SW-SMD_5P-L4.2-W2.8-P1.60-LS4.6-TR |  | KMR211GLFS | C&K | C221675 | LCSC
39 | 1 | Reset | SW301 | SW-SMD_5P-L4.2-W2.8-P1.60-LS4.6-TR |  | KMR211GLFS | C&K | C221675 | LCSC
40 | 1 | USB | TP200 | TESTPOINT-SMD
41 | 1 | VBAT | TP400 | TESTPOINT-SMD |  | KH-PG2012005-DZ | kinghelm(金航标) | C2842936 | LCSC
42 | 1 | +5V | TP401 | TESTPOINT-SMD |  | KH-PG2012005-DZ | kinghelm(金航标) | C2842936 | LCSC
43 | 1 | +3V3 | TP402 | TESTPOINT-SMD |  | KH-PG2012005-DZ | kinghelm(金航标) | C2842936 | LCSC
44 | 1 | 2.4GHz | U300 | WIRELM-SMD_ESP32-S3-WROOM-1 | 2.4GHz | ESP32-S3-WROOM-1-N16R8 | ESPRESSIF(乐鑫) | C2913202 | LCSC
45 | 1 | MPM3610GQV-Z | U400 | QFN-20_L5.0-W3.0-TL-MPM3610GQV-Z |  | MPM3610GQV-Z | MPS(芯源) | C5183856 | LCSC
46 | 1 | LD39200PUR | U401 | DFN-6_L3.0-W3.0-P0.95-BL-EP-1 |  | LD39200PUR | ST(意法半导体) | C2969757 | LCSC
47 | 1 | MAX98357AETE+T | U500 | TQFN-16_L3.0-W3.0-P0.50-BL-EP1.5 |  | MAX98357AETE+T | ADI(亚德诺)/MAXIM(美信) | C910544 | LCSC
48 | 1 | SMT-1028 | U501 | SMT-1028 |  | SMT-1028-T-2-R | PUI Audio, Inc. | 668-1532-1-ND | Digi-Key
49 | 1 | MPU-6050 | U600 | QFN-24_L4.0-W4.0-P0.50-BL-EP2.7 |  | MPU-6050 | TDK InvenSense(应美盛) | C24112 | LCSC
50 | 1 | LCD I2C | U700 | CONN-TH_4P-P2.00_S4B-PH-K-S-LF-SN |  | S4B-PH-K-S(LF)(SN) | JST | C157926 | LCSC
51 | 1 | SN74AHCT1G126DBVR | U701 | SOT-23-5_L3.0-W1.7-P0.95-LS2.8-BR |  | SN74AHCT1G126DBVR | TI(德州仪器) | C163712 | LCSC
52 | 1 | RGB | U702 | CONN-TH_3P-P2.00_S3B-PH-K-S-LF-SN |  | S3B-PH-K-S(LF)(SN) | JST | C157929 | LCSC
53 | 1 | 74LVC1G125GW | U800 | TSSOP-5_L2.1-W1.3-P0.65-LS2.2-BL |  | 74LVC1G125GW | Nexperia(安世) | C548256 | LCSC
54 | 1 | 74LVC1G126GW | U801 | TSSOP-5_L2.1-W1.3-P0.65-LS2.2-BL |  | 74LVC1G126GW | Nexperia(安世) | C548264 | LCSC
55 | 1 | USB4105-GF-A | USB200 | TYPE-C-SMD_SBC-160S1A-20-S412 |  | USB4105-GF-A | GCT | C3020560 | LCSC

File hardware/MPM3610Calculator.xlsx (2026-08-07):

MPM3610 Calculator
V_out | 5.10
R1 | 100000
R2 (computed) | 18549.51185
V_out (computed) | 5.15
R1 | 120000
R2 | 22000

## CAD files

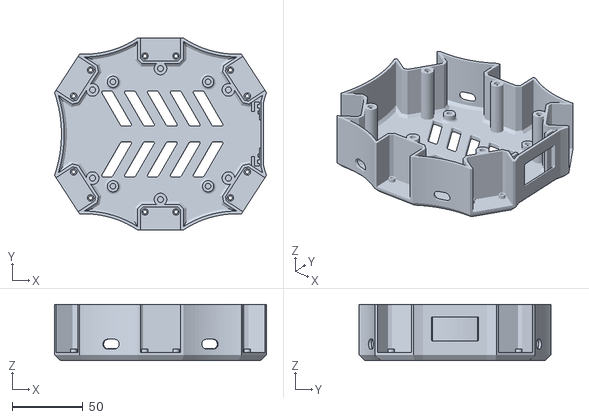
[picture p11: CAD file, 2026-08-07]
mechanics/stl/CenterBody-Main.stl
150.2 x 135.9 x 39.9

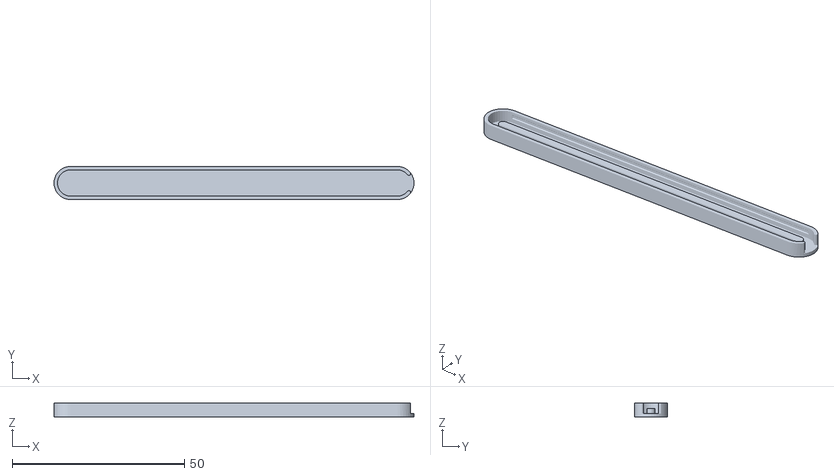
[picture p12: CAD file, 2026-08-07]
mechanics/stl/CenterBody-CoverLedHolder.stl
104.4 x 9.60 x 4.00

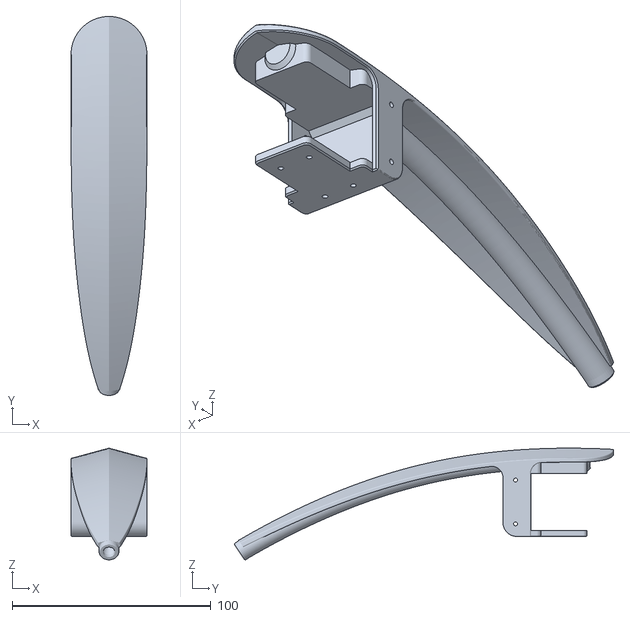
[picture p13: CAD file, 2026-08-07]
mechanics/stl/Tibia.stl
38.2 x 190.6 x 56.2

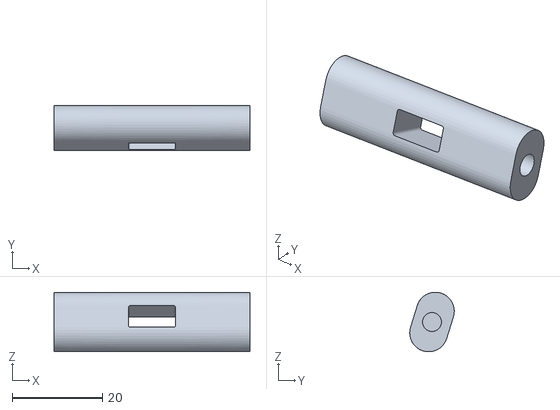
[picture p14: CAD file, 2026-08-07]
mechanics/stl/Femur-ConnectingBracket.stl
43.4 x 9.88 x 13.2

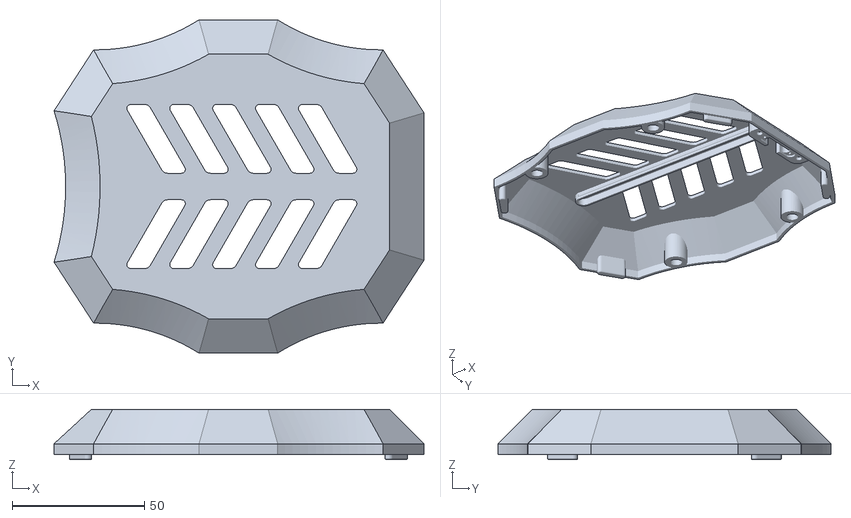
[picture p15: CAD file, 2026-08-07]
mechanics/stl/CenterBody-CoverWithDiffusor.stl
139.7 x 125.9 x 19.0

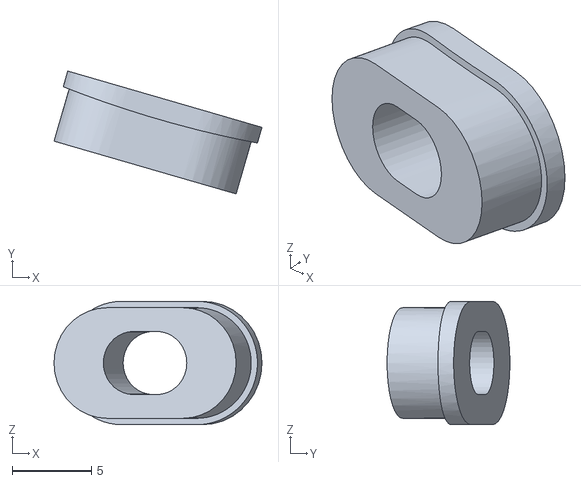
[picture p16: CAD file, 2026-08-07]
mechanics/stl/CenterBody-Grommet-2Cable.stl
13.2 x 7.77 x 7.80

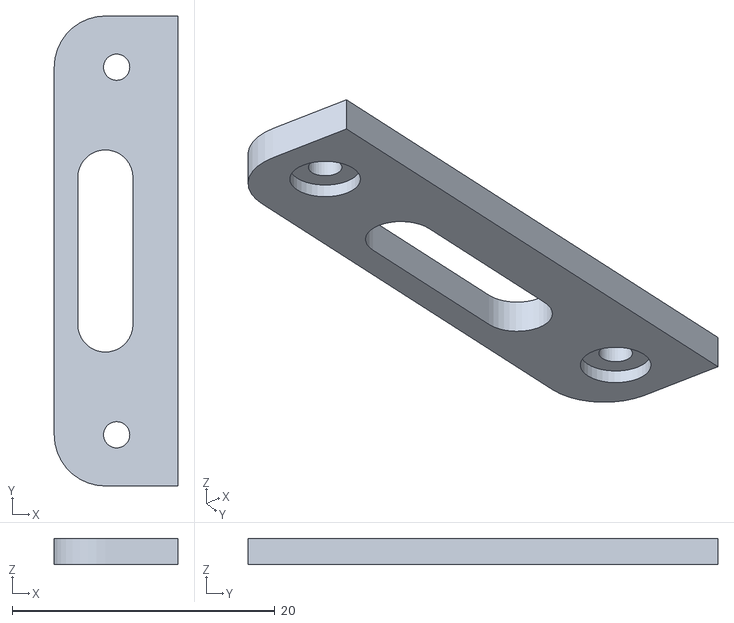
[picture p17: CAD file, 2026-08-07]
mechanics/stl/CenterBody-ConnectorCover.stl
9.42 x 35.8 x 2.00

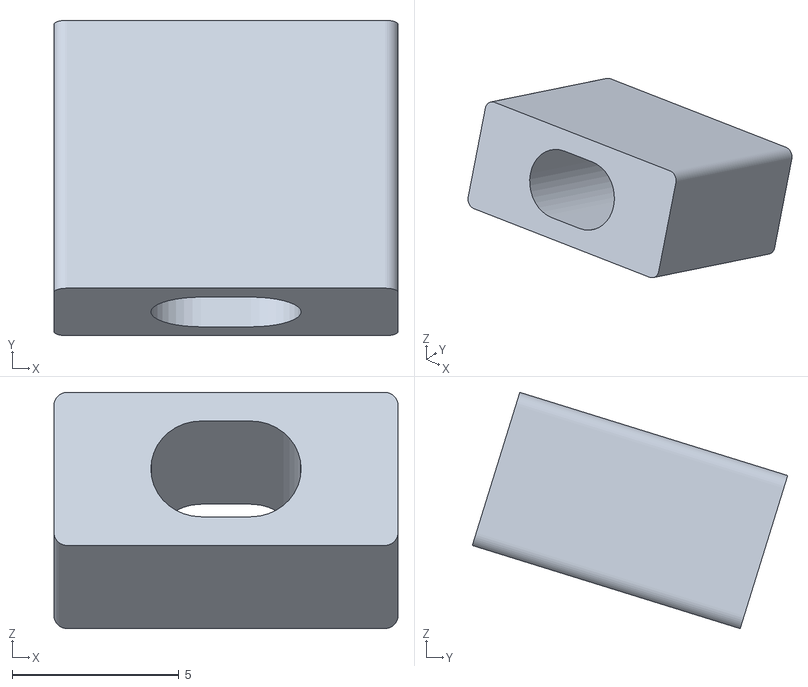
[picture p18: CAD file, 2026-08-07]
mechanics/stl/Femur-Groomet.stl
10.3 x 9.45 x 7.07

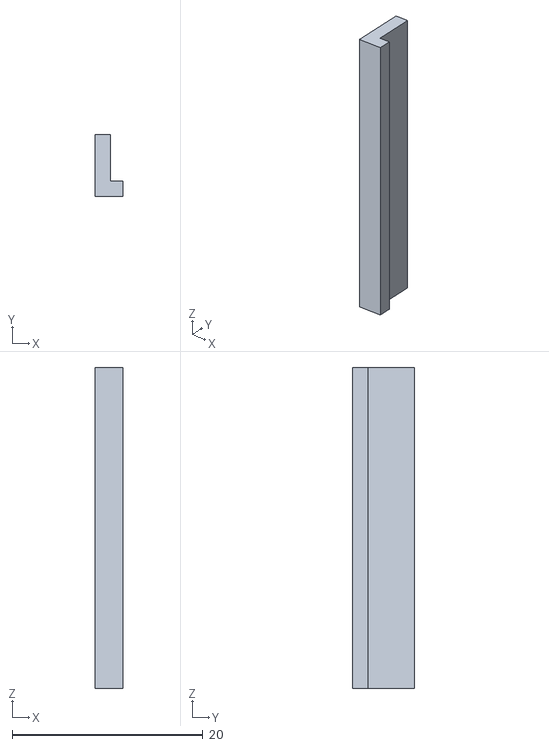
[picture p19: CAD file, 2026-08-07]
mechanics/stl/CenterBody-DisplayHolderRight.stl
2.90 x 6.50 x 33.7

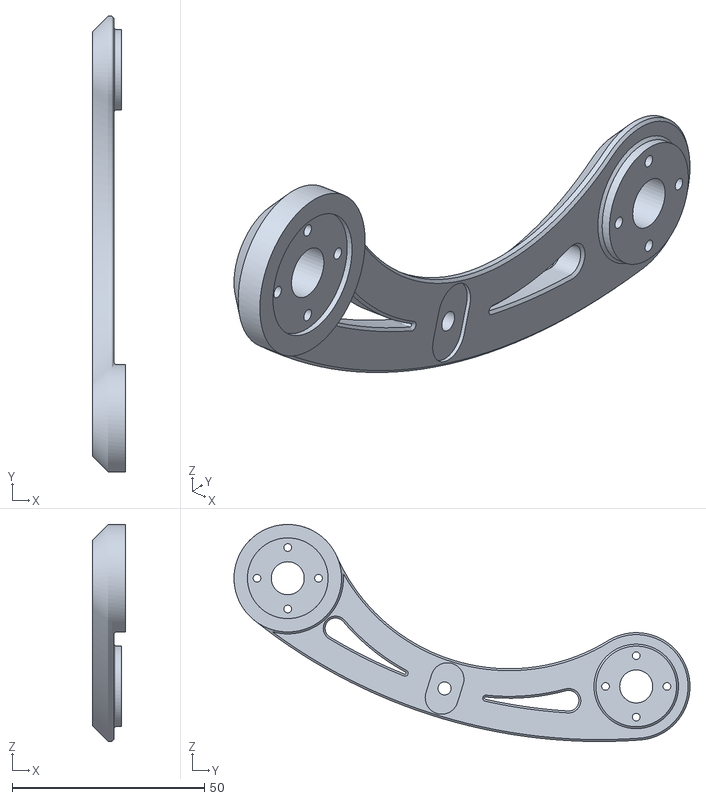
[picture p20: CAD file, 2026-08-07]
mechanics/stl/Femur-Bracket2.stl
8.50 x 118.7 x 56.5

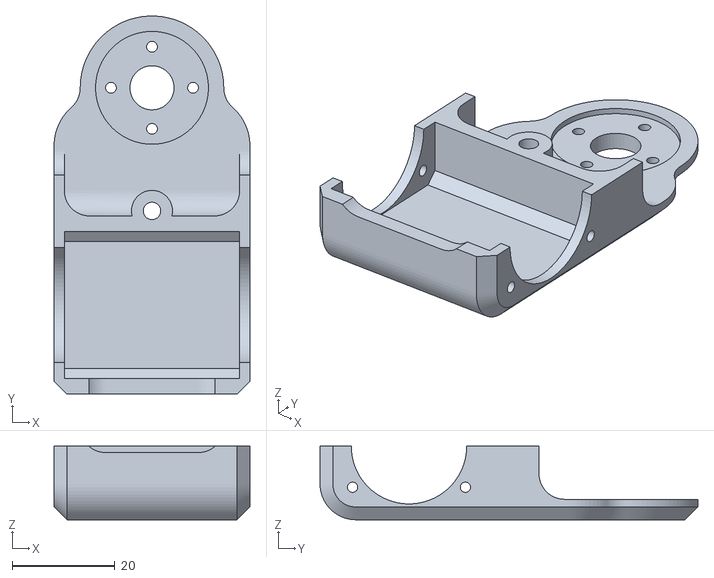
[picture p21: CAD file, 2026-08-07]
mechanics/stl/Coxa-Lower.stl
38.2 x 73.7 x 14.4

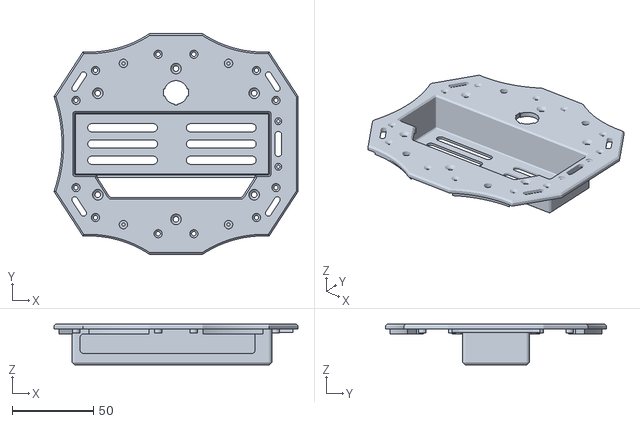
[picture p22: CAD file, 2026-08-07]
mechanics/stl/CenterBody-TopPlate.stl
150.2 x 135.9 x 25.0

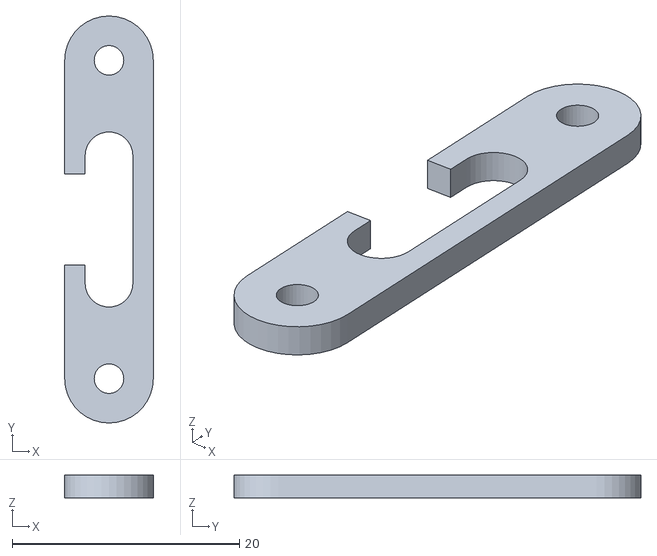
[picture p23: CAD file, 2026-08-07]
mechanics/stl/CenterBody-ConnectorTopPlate.stl
7.80 x 35.8 x 2.00

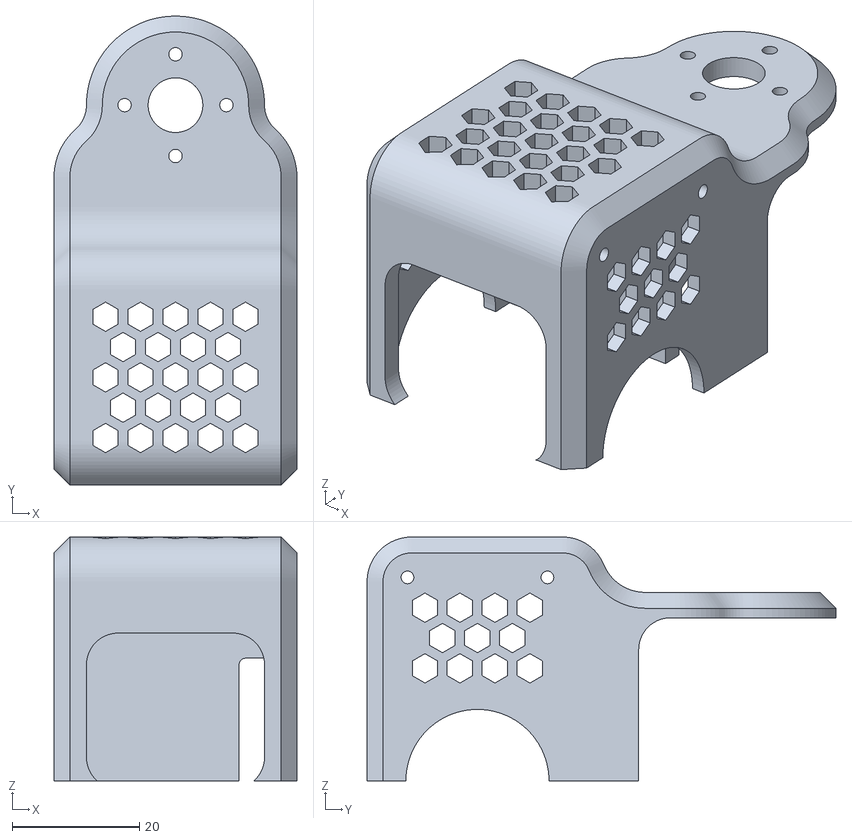
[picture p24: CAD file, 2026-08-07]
mechanics/stl/Coxa-Upper.stl
38.2 x 73.7 x 38.4

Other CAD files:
mechanics/stl/CenterBody-Grommet-1Cable.stl
mechanics/stl/CenterBody-DisplayHolderLeft.stl
mechanics/stl/CoxaTibia-CableFixture.stl
mechanics/stl/Femur-Bracket1.stl
mechanics/cad/Hexapod.f3z

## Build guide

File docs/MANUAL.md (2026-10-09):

# Operating manual

How to drive the hexapod. This assumes the robot is built, the servos have their IDs and baud
rate, and both it and the transmitter are flashed. For building and setup, see the
[top-level README](../README.md) and [`software/README.md`](../software/README.md).

Everything below is behaviour of `software/Hexapod/`. Where a number matters it is named, so
you can find and change it.

- [First-time setup](#first-time-setup)
- [Controls at a glance](#controls-at-a-glance)
- [Starting up](#starting-up)
- [The five things it does](#the-five-things-it-does)
- [Walking](#walking)
- [Tuning the gait while walking](#tuning-the-gait-while-walking)
- [Posing](#posing)
- [Balancing](#balancing)
- [Reading the robot](#reading-the-robot)
- [Timeouts and what stops on its own](#timeouts-and-what-stops-on-its-own)
- [When something is wrong](#when-something-is-wrong)

## First-time setup

Done once, per robot. A Dynamixel leaves the factory as **ID 1 at 57600 baud**, so eighteen
new servos are eighteen devices with the same address — they have to be given identities one
at a time before they can share a bus.

The sketches for this are in [`software/DynamixelUtilities/`](../software/DynamixelUtilities).
Each talks to the servo bus and nothing else, so you can run them on the assembled controller
board with the rest of the robot inert.

> **Connect exactly one servo while setting its baud rate and ID.** Both sketches scan the bus
> and write to whatever they find. With a whole bus connected, all eighteen end up identical —
> which is the state you started from, only now at the wrong baud rate too.

### 1. Baud rate — `SetBaudRate/`

The firmware runs the bus at **3,000,000 baud**. The sketch scans 9600 through 4.5 M, finds
the servo whatever speed it is at, and moves it to `cTargetBaudRate` — already 3000000, so
there is nothing to edit unless you are changing the bus speed itself.

### 2. ID — `SetID/`

The sketch finds the servo, then prompts on the serial monitor: type the new ID and press
enter. The scheme is **tens digit = leg, units digit = joint**:

| | Coxa | Femur | Tibia |
|---|---|---|---|
| **Right front** | 11 | 12 | 13 |
| **Right middle** | 21 | 22 | 23 |
| **Right rear** | 31 | 32 | 33 |
| **Left front** | 41 | 42 | 43 |
| **Left middle** | 51 | 52 | 53 |
| **Left rear** | 61 | 62 | 63 |

Right side is 1–3, left side is 4–6, front to rear in both cases. This table is the one in
`Hexapod.cpp` (`cServoConfig`); if you renumber, that is the place to change it, and a
`static_assert` will catch a table with the wrong number of entries.

### 3. Mechanical zero — `DefaultPosition/`

Sends **2048** — the centre of the 12-bit range, and 0° to the kinematics — to every servo on
the bus, and holds it. **Assemble each joint with the servo held at 2048**, so that the horn
sits where the maths assumes it does.

This is the step that decides whether the robot stands straight. A joint assembled one spline
tooth off is a permanent angular offset the firmware has no way to know about.

### 4. The transmitter

Its joysticks and IMU are calibrated from its own menu (Switch 1), and the settings are stored
in the transmitter, not the robot. See the
[transmitter repository](https://github.com/forgevolt/Transmitter). Uncalibrated sticks show
up as a robot that drifts with the sticks centred.

Nothing needs pairing by hand — the two ends find each other on their own.

## Controls at a glance

The transmitter shows a label for each switch and button, sent by the robot, so the screen is
always the authority. This is what those labels mean.

| Control | Label | Does |
|---|---|---|
| **Switch 1** | *(blank)* | Opens the transmitter's own menu. The robot ignores it |
| **Switch 2** | `Adjust Gait` | Hold: the right stick tunes step length, height and ground clearance instead of steering |
| **Switch 3** | `Posing` | On: pose the body with the feet planted |
| **Switch 4** | `Balance` | On: the robot levels itself against the ground |
| **Left button** | `Stand up` / `Park` | Stands up from parked, or parks from anything else |
| **Right button** | `Change Gait` / `Level IMU` | While walking, cycles tripod → tetrapod → ripple. In Ready, sets what the robot takes as level (see [Balancing](#balancing)) |

A button label is **blank whenever the button does nothing** — during a stand-up or park
transition, for instance. That is deliberate feedback, not a fault.

### Sticks while walking

| Axis | Two-joystick transmitter | One-joystick transmitter |
|---|---|---|
| Left X | strafe left / right | strafe left / right |
| Left Y | forward / backward | forward / backward |
| Left Z (twist) | — | **turn** (yaw) |
| Right X | **turn** (yaw) | — |
| Right Y | ride height, springs back to centre | — |
| Right Z (twist) | — | — |

The two variants differ in exactly one place: yaw comes from the left stick's twist axis on
the one-joystick transmitter and from the right stick's X axis on the two-joystick one. The
robot picks the mapping from the device type the transmitter announces at pairing — there is
nothing to configure.

Speed is not a separate control. **How far you push the stick sets how fast the gait cycles**,
between `cMinDurationMS` and `cMaxDurationMS`. Push gently and it walks slowly.

## Starting up

1. **Switch on.** The on/off switch feeds servo power. Until it is on, the robot sits in its
   off state with torque released, the display blank and the LEDs dark.
2. **The startup sound plays** and the legs fold to the parked position, taking about 3 s
   (`cParkDurationMs`).
3. **The LEDs pulse red** and the eyes look tired. The robot is waiting for the transmitter.
4. **Pairing happens by itself.** The robot broadcasts, the transmitter answers. Once frames
   are flowing the eyes open to their normal state and the robot is ready.
5. **Press the left button** (`Stand up`) to stand.

Nothing needs to be switched on in a particular order. If the transmitter is already on when
the robot boots, pairing completes as soon as the robot is up.

**Keep the robot still while it boots.** The IMU calibrates its gyro then, which needs the
robot still but not level. The very first boot also sets what the robot takes as level, so do
that one on a level floor (see [Balancing](#balancing)).

## The five things it does

Internally these are states, and they explain why a control sometimes does nothing.

```mermaid
flowchart TD
    Off["Off"] -->|"power switch on"| Init["Initializing"]
    Init -->|"power switch off"| Off
    Init -->|"transmitter paired"| Ready["Ready"]
    Ready -->|"left button"| Standing["Standing"]
    Standing -->|"left button<br>30 s idle"| Ready
    Standing -->|"move a stick"| Walking["Walking"]
    Walking -->|"15 s idle"| Standing
    Walking -->|"right button:<br>next gait"| Walking
    Standing -->|"Switch 3 on"| Posing["Posing"]
    Posing -->|"Switch 3 off"| Standing
    Standing -->|"Switch 4 on"| Balancing["Balancing"]
    Balancing -->|"Switch 4 off"| Standing

    N["<b>From Standing, Walking, Posing or Balancing</b><br>the <b>left button</b> parks the robot → Ready<br>a <b>lost link</b> or the <b>power switch off</b> → Initializing<br>&nbsp;<br>Switch 3 and Switch 4 also work <b>while walking</b>,<br>and Switch 3 works while balancing."]
    Off ~~~ N

    classDef s_off  fill:#E7E9EC,stroke:#3A4048,stroke-width:2px,color:#1A1E24
    classDef s_init fill:#FDE7D6,stroke:#E8590C,stroke-width:2px,color:#1A1E24
    classDef s_stnd fill:#FFF3BF,stroke:#B58B00,stroke-width:2px,color:#1A1E24
    classDef s_walk fill:#D9F2E0,stroke:#2B8A3E,stroke-width:2px,color:#1A1E24
    classDef s_mode fill:#E3E9FB,stroke:#3A56A8,stroke-width:2px,color:#1A1E24
    classDef s_note fill:#FFFDF3,stroke:#B58B00,stroke-width:1.5px,color:#1A1E24
    class Off s_off
    class Init,Ready s_init
    class Standing s_stnd
    class Walking s_walk
    class Posing,Balancing s_mode
    class N s_note
```

| State | How you get there | What it is |
|---|---|---|
| **Off** | on/off switch off | Torque released, display blank |
| **Initializing** | power on, or the link drops | Legs folding to parked; controls ignored |
| **Ready** | parked, transmitter paired | On the ground, waiting. `Stand up` and `Level IMU` available |
| **Standing** | left button from Ready | Legs deployed, chassis level, ready to walk |
| **Walking** | move a stick from Standing | Gait running |
| **Posing** | Switch 3 | Feet planted, body moves |
| **Balancing** | Switch 4 | Feet planted, robot levels itself |

Walking, posing and balancing all return to Standing when you release what put you there.
The left button parks from any of them.

The same machine with the guards, gaits and constants from `Hexapod.cpp` is in
[`state-machine-detail.md`](state-machine-detail.md).

**Transitions cannot be interrupted, and presses during one are dropped rather than queued.**
A park takes 3 s; acting on a button pressed three seconds ago is not what you would expect,
so both button labels go blank until the robot is ready to listen again.

## Walking

From Standing, **any stick movement starts walking** — there is no separate command. Push the
left stick and it goes.

Three gaits, cycled with the right button while walking:

| Gait | Character |
|---|---|
| **Tripod** | Three legs at a time. Fastest, least stable |
| **Tetrapod** | Two at a time. A good default |
| **Ripple** | One at a time. Slowest, most stable, best on rough ground |

The gait change takes effect at the end of the current cycle, not instantly — the robot
finishes the step it is in. The transmitter shows the current gait as `Gait Type`.

Release the sticks and the gait runs out its remaining phase and stops with the feet down. It
does not freeze mid-step.

## Tuning the gait while walking

**Hold Switch 2** (`Adjust Gait`) and the right stick stops steering and starts tuning. The
three values change while you hold the stick over and stay where you leave them:

| Axis | Tunes | Effect | Range |
|---|---|---|---|
| Right X | Step length | How far each foot travels — stride | 20–150 mm |
| Right Y | Ground clearance | Ride height. Up raises the body | 60–150 mm |
| Right Z (twist) | Step height | How high a foot lifts in swing | 40–70 mm |

All three are clamped to their configured ranges, and the transmitter shows the live values as
`Step Length`, `Clearance` and `Step Height`. Steering is disabled while Switch 2 is held —
yaw is explicitly zeroed, so the robot walks straight while you tune.

**Ground clearance behaves differently depending on the switch.** With Switch 2 held, the
right stick's Y axis *sets* the tuned value and it persists. Without it, the same axis only
*trims* — centring the stick springs the body back to the tuned height. That is why you can
duck under something without losing your ride-height setting.

While Switch 2 is held, the robot ignores the idle timeout. You can take as long as you like.

## Posing

**Switch 3 on**: the feet plant and the body moves independently of them.

| Axis | Moves the body |
|---|---|
| Left X | sideways |
| Left Y | forward / backward |
| Left Z (twist) | up / down |
| Right X | roll |
| Right Y | pitch |
| Right Z (twist) | yaw |

**With Switch 4 also on, roll and pitch come from the transmitter's own tilt instead of the
right stick.** Tilt the transmitter and the body follows it. Rotation is clamped to the same
limits as stick control, so it cannot be driven further than the legs allow.

All pose motion is heavily filtered — roughly a second to settle for translation, ¾ of a
second for rotation. It will feel soft rather than immediate; that is intentional, to keep the
servos gentle.

Turn Switch 3 off and the robot stands back up.

## Balancing

**Switch 4 on** (with Switch 3 off): `LevelGait` reads the onboard IMU and counters chassis
tilt, so the body stays level while the feet stay planted. Put the robot on a slope, or tilt
the surface under it, and it compensates.

Correction is clamped to about 20° (`cMaxCorrection`) and smoothed on top of the IMU's own
filtering, so a jumpy reading does not produce jumpy servos.

**What it takes as level** is stored on the robot and survives a reboot, so booting on a slope
does not matter. If it holds its body slightly tilted on flat ground, put it on a level floor
and press the right button (`Level IMU`) while it is Ready: the chassis rests on the floor
then, so the IMU sits exactly as flat as the floor. The signal sound confirms it. `Level IMU`
needs the two-joystick transmitter, since the one-joystick version has no right button. The
very first boot sets this reference by itself.

If the IMU does not answer at boot, the robot shows `IMU INIT FAILED` and levelling is off for
that run: Switch 4 then leaves the robot standing without correcting.

The robot does not walk while balancing. Turn Switch 4 off to stand normally.

## Reading the robot

You can tell its state without looking at the transmitter.

### LEDs

| Effect | Means |
|---|---|
| **Pulsing red** | Initializing, Ready, or Standing — not moving |
| **Pulsing orange** | Posing or Balancing |
| **Sweeping backward** | Walking forward |
| **Sweeping forward** | Walking backward |
| **Sweeping to the middle** | Strafing or turning |
| Dark | Off — or in the walking state with the sticks centred |

The strip is mounted rotated 180°, which is why the sweep names look inverted in the source.

### Eyes

| Look | State |
|---|---|
| Blank | Off |
| Tired, still | Initializing |
| Normal, idle animation | Ready |
| Normal, larger, curious | Standing |
| Happy | Posing or Balancing |
| Focused, narrowed | Walking |

While walking the eyes track your steering stick, so they look the way the robot is being
sent. Under `Adjust Gait` they track the left stick regardless.

### The transmitter screen

Four live values from the robot: `Clearance`, `Step Length`, `Step Height` and `Gait Type`.
They are sent only when they change.

## Timeouts and what stops on its own

| After | What happens | Constant |
|---|---|---|
| 250 ms without a control frame | The link counts as lost; the robot parks | `cControlDataTimeoutMs` |
| 15 s of no stick input while walking | Returns to Standing | `cIdleTimeout` |
| 30 s standing | Parks itself | `2 × cIdleTimeout` |
| 60 s parked and idle | Servo torque released | `cWaitTimeUntilTorqueOff` |

**Torque release is not a fault.** The robot goes limp on purpose, to keep 18 servos from
cooking while nothing is happening. It re-engages on the next command.

**Losing the link parks the robot rather than freezing it.** Walk out of range, switch the
transmitter off, or flip the on/off switch mid-walk, and the legs fold to parked and the state
machine returns to Initializing. It re-pairs by itself when the transmitter comes back.

## When something is wrong

The OLED shows faults as a crossed-eye face with two lines of text, overriding the eyes.

| On screen | Means | Do |
|---|---|---|
| `SERVO INIT FAILED` / `check servo bus` | The servo bus did not come up at boot | Check power and the bus wiring. **Do not command a stand** — the state machine will still reach Ready and let you try |
| `ABNORMAL RESET` / *reason* | The last run ended in a panic, watchdog or brownout, not a clean power-off | Clears itself after 20 s. `brownout` means the supply dipped: suspect the battery or a stall |
| `IMU INIT FAILED` / `levelling disabled` | The IMU did not answer at boot | Clears itself after 20 s. Everything works except balancing. Check the I2C wiring to the IMU |
| `SERVO READ FAILED` / `torque stays off` | The servo positions could not be read when torque was due to come on, so the legs stay limp rather than jump to stale positions | Clears itself after 20 s. The next park or stand-up reads again. If it repeats, check the bus wiring and servo power |
| `SERVO READ FAILED` / `check servo bus` | A position read failed while torque was on, e.g. a leg's bus cable came loose. The legs that answer park from where they were told to be | Clears itself after 20 s. Check the bus wiring and servo power, then switch off and on |
| `BATTERY LOW` / *voltage* | The pack has dropped below 10.5 V (3.5 V per cell), smoothed over a few seconds | Shown for 20 s with the error tone, and again every minute while the pack stays low. Park and swap or charge the pack |

The error tone plays with the servo init, reset and battery faults, not with the IMU or servo read ones.

### Symptoms without a fault message

**Nothing responds, LEDs pulsing red.** No link. The robot never left Initializing — check the
transmitter is on and that both ends are on the same protocol version. A version mismatch is
logged at pairing over USB serial.

**Buttons show blank labels and do nothing.** A transition is running. Wait ~3 s.

**It walks but will not turn.** Switch 2 is on. Yaw is disabled while tuning.

**It stands but sags, or a leg does not reach.** IK targets outside the reachable workspace are
clamped rather than refused. Connect USB and watch the serial log: unreachable targets and
clamped goals are counted and reported once a second, with the worst leg and the overshoot in
millimetres. Silence there means nothing was clamped.

**It parks itself while you are still driving.** Check the 250 ms link timeout first — brief
radio dropouts look exactly like this.

### Serial log

Connect USB and open the monitor at **115200 baud**. The robot detects the USB connection at
boot and only then waits for the port and logs verbosely; on battery it boots straight through
and logs warnings only. Every state change is printed, which is usually enough to see what it
thought you asked for. Every 10 s it also prints the battery voltage.

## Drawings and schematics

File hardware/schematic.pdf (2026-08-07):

Drawn
VER

Create Date

PAGE | OF

Schematic

Update Date

SIZE

Page

2026-06-05

## 2026-04-06 Hexapod_R2

## Overview

# Hobbyist

## Christoph Streit

1 | A4

# Microcontroller

# Audio & IMU

Sheet: USB | Sheet: ESP32
2 | 3

# Sheet: Audio

5

I/O

# Sheet: IO

7

# Power

# Sheet: Power

4

6 | 8
Sheet: IMU | Sheet: Dynamixel

# ESD Protection

# USB

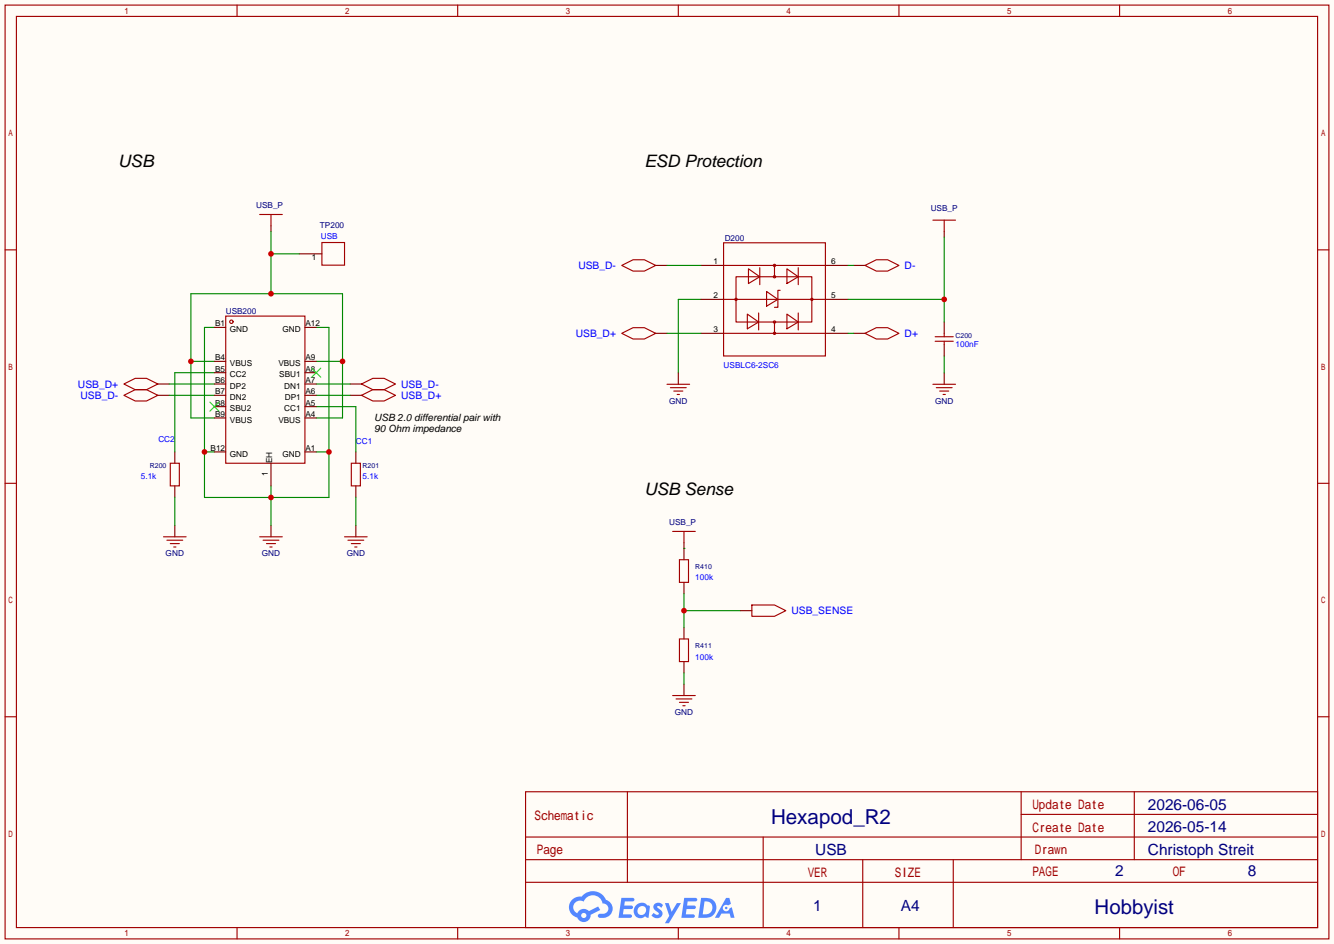
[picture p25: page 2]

# ESP32--S3-WROOM-1-N16R8

# Boot Option and Reset Button

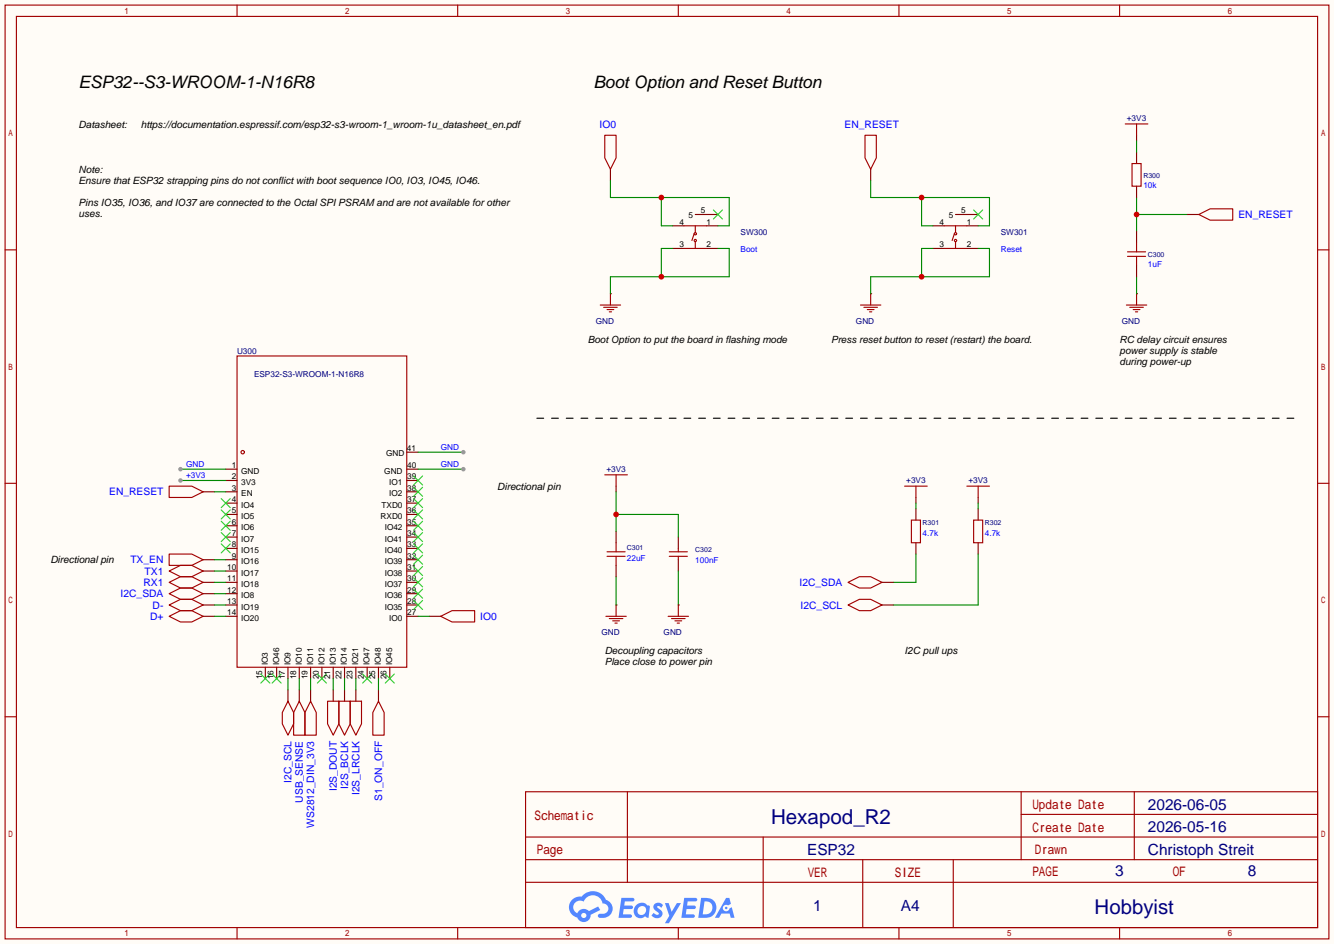
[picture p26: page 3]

https://documentation.espressif.com/esp32-s3-wroom-1_wroom-1u_datasheet_en.pdf

Note:
Ensure that ESP32 strapping pins do not conflict with boot sequence IO0, IO3, IO45, IO46.
Pins IO35, IO36, and IO37 are connected to the Octal SPI PSRAM and are not available for other
uses.

GND
Boot Option to put the board in flashing mode

Press reset button to reset (restart) the board.

RC delay circuit ensures
power supply is stable
during power-up

Decoupling capacitors
Place close to power pin

Battery/LIPO | Net Tie and Indicator LEDs

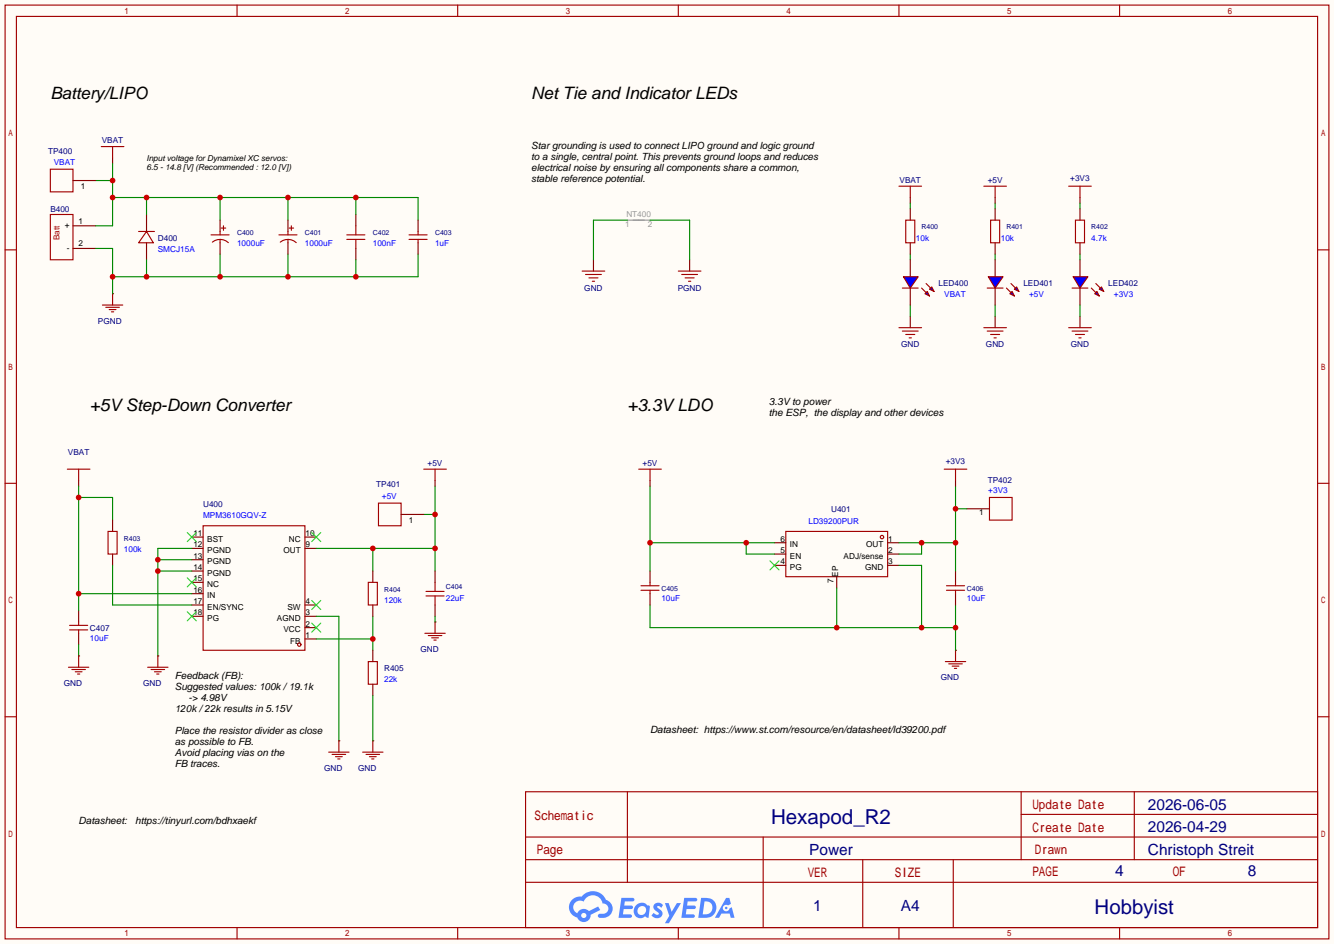
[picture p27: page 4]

Star grounding is used to connect LIPO ground and logic ground
to a single, central point. This prevents ground loops and reduces
electrical noise by ensuring all components share a common,
stable reference potential.

Input voltage for Dynamixel XC servos:
6.5 - 14.8 [V] (Recommended : 12.0 [V])

the ESP, the display and other devices

Feedback (FB):
GND
Suggested values: 100k / 19.1k
120k / 22k results in 5.15V
Place the resistor divider as close
as possible to FB.
Avoid placing vias on the

Datasheet: https://www.st.com/resource/en/datasheet/ld39200.pdf

Datasheet: https://tinyurl.com/bdhxaekf

## Gain Selection

## Amplifier

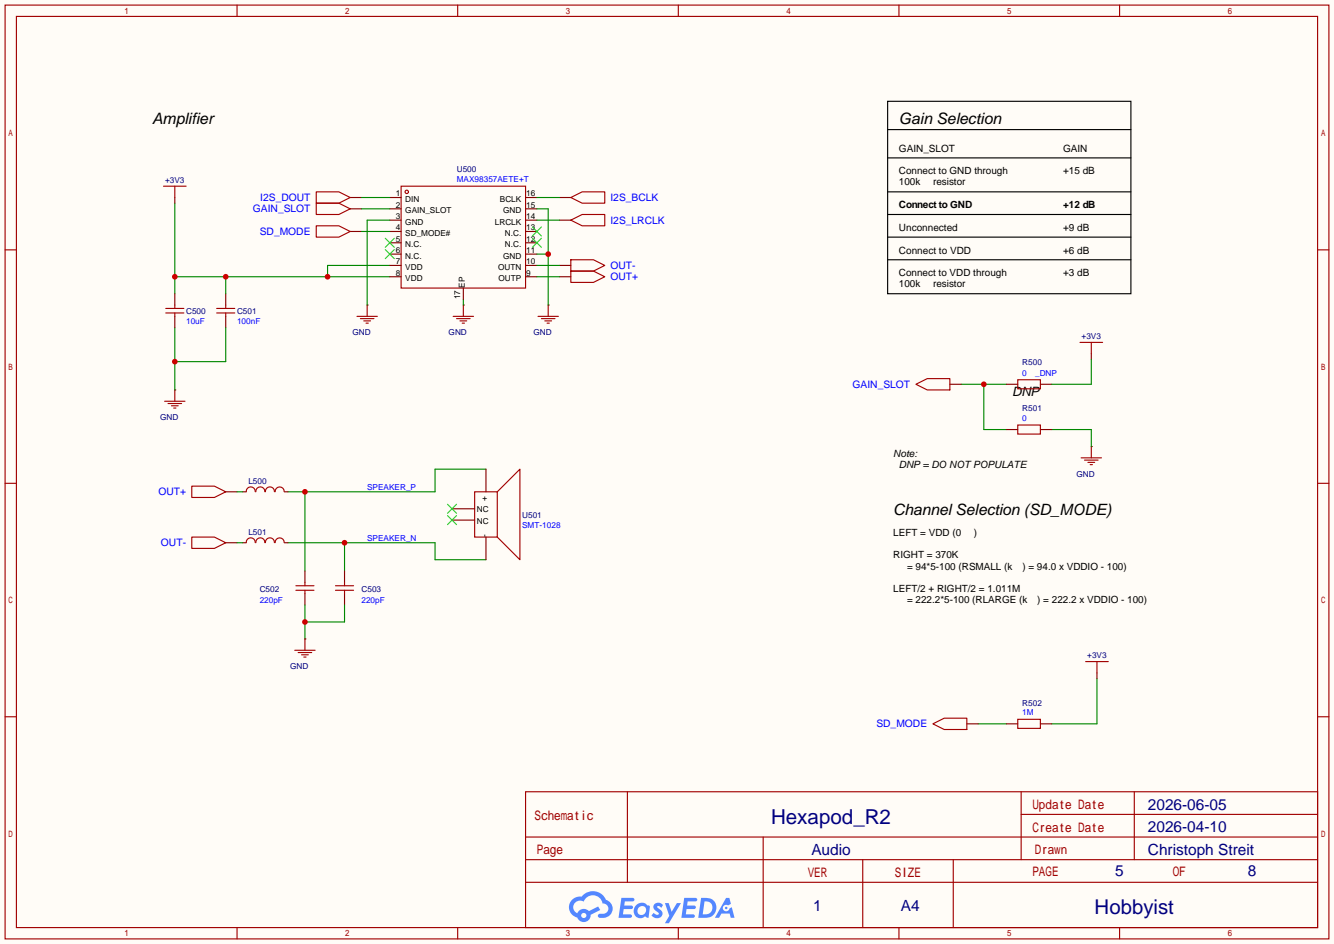
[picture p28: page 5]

Connect to GND through
100k resistor
Connect to GND
Unconnected
Connect to VDD
Connect to VDD through

Note:
DNP = DO NOT POPULATE

## IMU

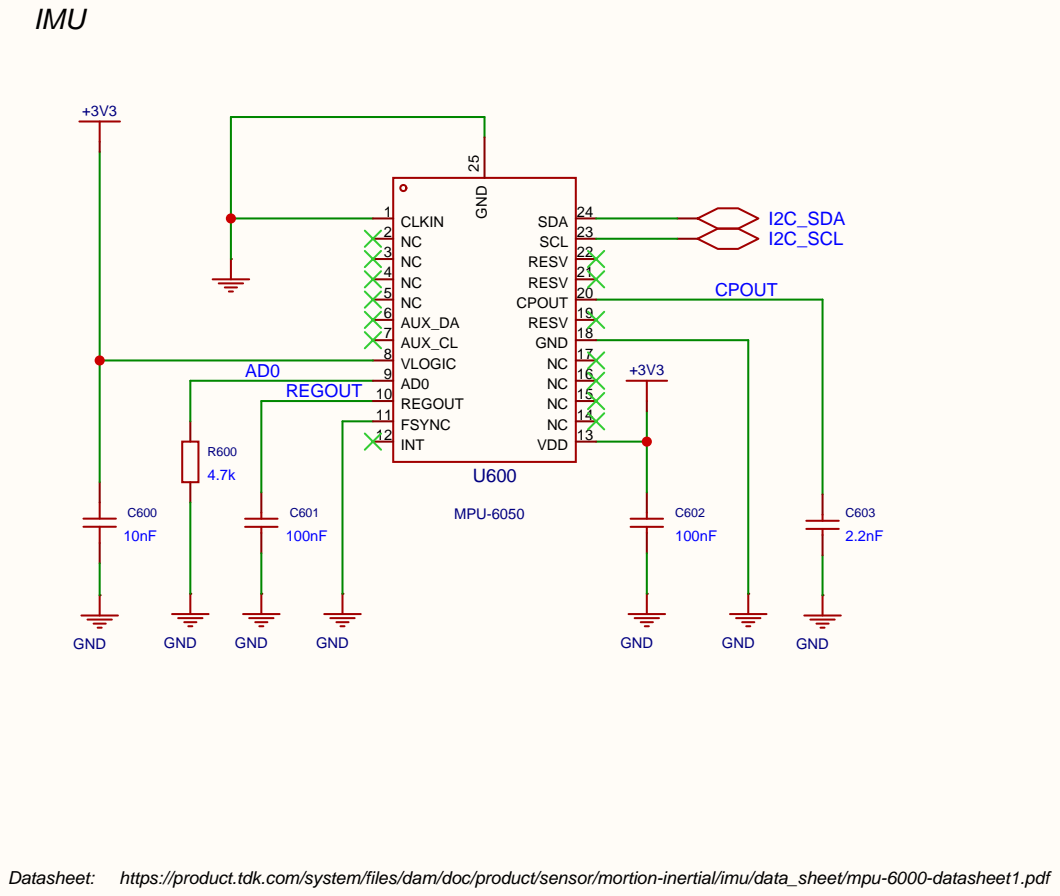
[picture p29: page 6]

Datasheet: https://product.tdk.com/system/files/dam/doc/product/sensor/mortion-inertial/imu/data_sheet/mpu-6000-datasheet1.pdf

# On/Off

# M3 Mounting Holes

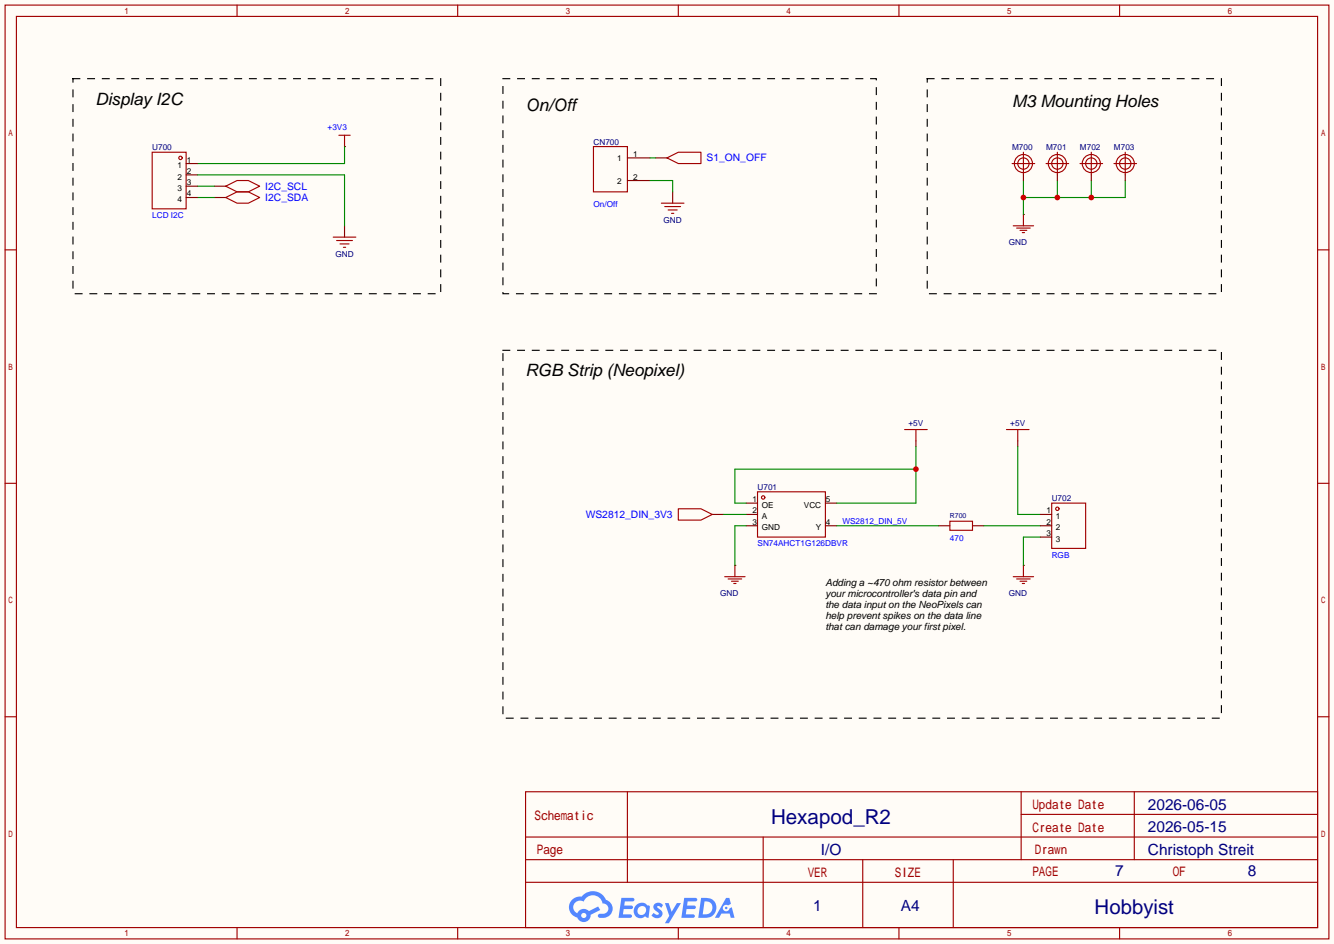
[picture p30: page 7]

Adding a ~470 ohm resistor between
your microcontroller's data pin and
the data input on the NeoPixels can
help prevent spikes on the data line
that can damage your first pixel.

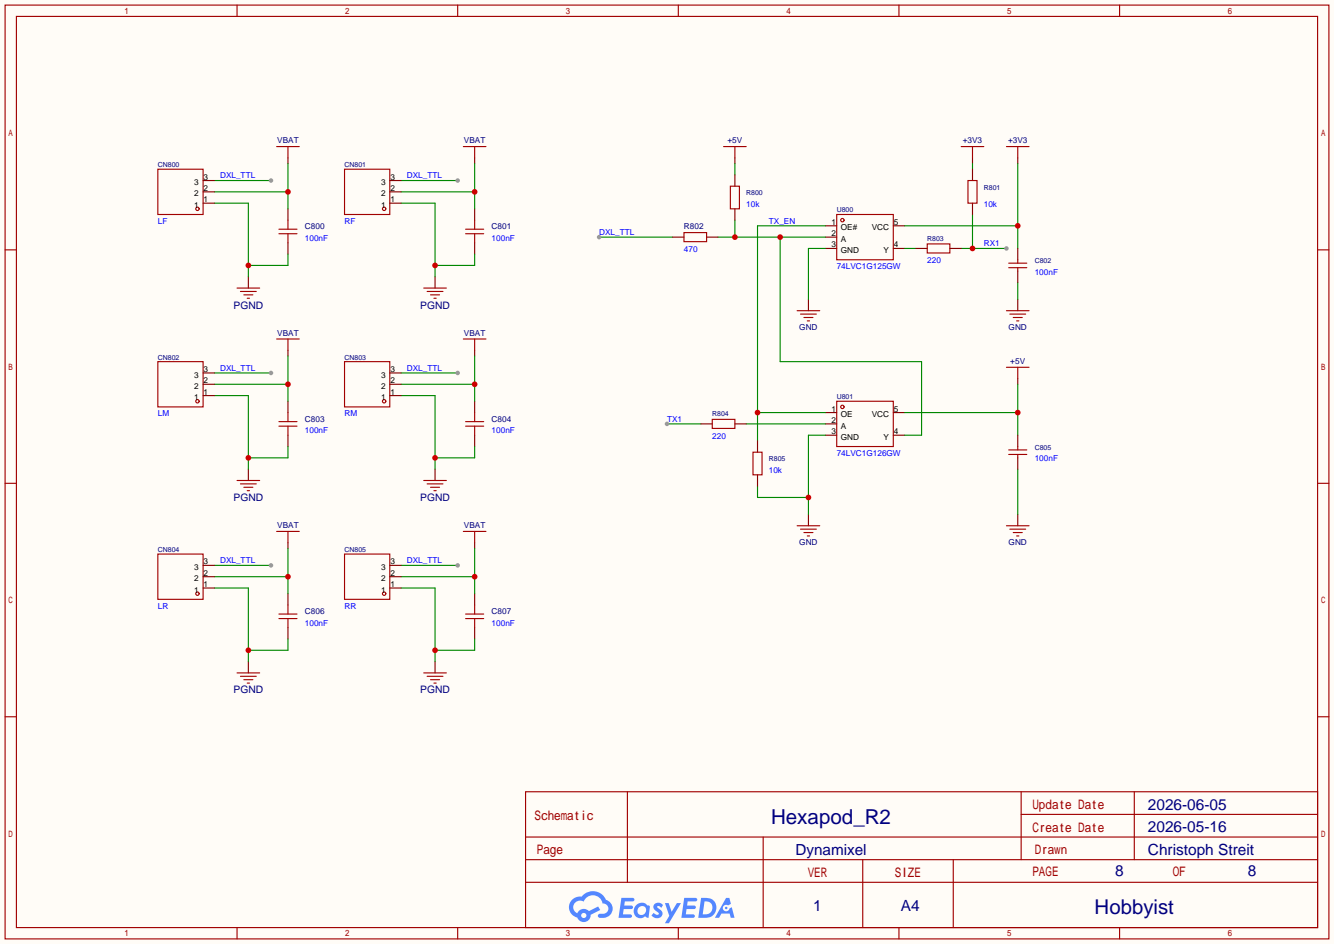
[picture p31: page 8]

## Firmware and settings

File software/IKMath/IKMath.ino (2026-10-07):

// ---------------------------------------------------------------------------------------------
// IKMath — Standalone inverse kinematics implementation, decoupled from the hexapod robot 
//          to simplify debugging.
//
//          Christoph Streit - 2026
// ---------------------------------------------------------------------------------------------

#include <Streaming.h>
#include "ServoBus.h"
#include <VectorUtilities.h>
using namespace vectorutilities;
#include "Leg.h"

constexpr int cDXLDirPin = 16; 
constexpr int cDXL_RX    = 18; 
constexpr int cDXL_TX    = 17;

ServoBus servoBus(cDXLDirPin, cDXL_RX, cDXL_TX);

// Joint limits as in software/Hexapod/Hexapod.cpp.
const int32_t cMinCoxa  = 1200, cMaxCoxa  = 3000;
const int32_t cMinFemur = 900,  cMaxFemur = 3500;
const int32_t cMinTibia = 200,  cMaxTibia = 2700;

Leg leftFront(LegId::LF,  servoBus, 0, 1, 2);
Leg leftMiddle(LegId::LM, servoBus, 3, 4, 5);
Leg leftRear(LegId::LR,   servoBus, 6, 7, 8);

Leg rightFront(LegId::RF,  servoBus, 9, 10, 11); 
Leg rightMiddle(LegId::RM, servoBus, 12, 13, 14);
Leg rightRear(LegId::RR,   servoBus, 15, 16, 17);


// ---------------------------------------------------------------------------------------------
void setup() 
{
  Serial.begin(115200);

  unsigned long startTime = millis();
  while (!Serial && (millis() - startTime < 1000))
    delay(10);

  Serial << "\n\nSW version from " << __DATE__ << " " << __TIME__ << endl;
  
  esp_log_level_set("*", ESP_LOG_VERBOSE);

  servoBus.configureServo(0, 41, cMinCoxa,  cMaxCoxa);  // LF
  servoBus.configureServo(1, 42, cMinFemur, cMaxFemur);
  servoBus.configureServo(2, 43, cMinTibia, cMaxTibia);

  servoBus.configureServo(3, 51, cMinCoxa,  cMaxCoxa);  // LM
  servoBus.configureServo(4, 52, cMinFemur, cMaxFemur);
  servoBus.configureServo(5, 53, cMinTibia, cMaxTibia);

  servoBus.configureServo(6, 61, cMinCoxa,  cMaxCoxa);  // LR
  servoBus.configureServo(7, 62, cMinFemur, cMaxFemur);
  servoBus.configureServo(8, 63, cMinTibia, cMaxTibia);

  servoBus.configureServo(9,  11, cMinCoxa,  cMaxCoxa);  // RF
  servoBus.configureServo(10, 12, cMinFemur, cMaxFemur);
  servoBus.configureServo(11, 13, cMinTibia, cMaxTibia);

  servoBus.configureServo(12, 21, cMinCoxa,  cMaxCoxa);  // RM
  servoBus.configureServo(13, 22, cMinFemur, cMaxFemur);
  servoBus.configureServo(14, 23, cMinTibia, cMaxTibia);

  servoBus.configureServo(15, 31, cMinCoxa,  cMaxCoxa);  // RR
  servoBus.configureServo(16, 32, cMinFemur, cMaxFemur);
  servoBus.configureServo(17, 33, cMinTibia, cMaxTibia);

  servoBus.begin();

  // Hold where the servos are before enabling torque, as ServoBus.h requires: otherwise each
  // servo would drive to whatever stale goal its own register still holds.
  servoBus.syncReadPresentPosition();
  for (int i = 0; i < ServoBus::cNumServos; i++)
    servoBus.setGoalPosition(i, servoBus.presentPosition(i));
  servoBus.syncWrite();

  servoBus.setSafeTorque();
}

// ---------------------------------------------------------------------------------------------
void loop() 
{
// Sitting 2048, 3213, 2351
//  LF  208.94,  135.67, 41.60
//  LM  0.00,    238.13, 41.60
//  LR  -208.94, 135.67, 41.60
// Standing 1 2048, 2274, 1932
//  LF  247.70, 160.85,  -85.22
//  LM  0.00,   284.35,  -85.22
//  LR  -247.70, 160.85, -85.22
// Standing 2 2048, 2426, 2222
//  LF  201.14,  130.61, -75.33
//  LM  0.00,    228.84, -75.33
//  LR  -201.14, 130.61, -75.33


  // Sitting 
  leftFront.setPosition(Vector3(227, 147.5, 50));
  leftMiddle.setPosition(Vector3(0,  260, 50));
  leftRear.setPosition(Vector3(-227, 147.5, 50));

  rightFront.setPosition(Vector3(227, -147.5, 50));
  rightMiddle.setPosition(Vector3(0,  -260, 50));
  rightRear.setPosition(Vector3(-227, -147.5, 50));

  // Standing
  // leftFront.setPosition(Vector3(227, 147.5, -90));
  // leftMiddle.setPosition(Vector3(0,  260, -90));
  // leftRear.setPosition(Vector3(-227, 147.5, -90));

  // rightFront.setPosition(Vector3(227, -147.5, -90));
  // rightMiddle.setPosition(Vector3(0,  -260, -90));
  // rightRear.setPosition(Vector3(-227, -147.5, -90));

  // Standing twisted
  // leftFront.setPosition(Vector3(186, 150, -90));
  // leftMiddle.setPosition(Vector3(0,  229, -90));
  // leftRear.setPosition(Vector3(-186, 150, -90));

  // rightFront.setPosition(Vector3(186, -150, -90));
  // rightMiddle.setPosition(Vector3(0,  -229, -90));
  // rightRear.setPosition(Vector3(-186, -150, -90));

  // 10 deg twisted -> more reach
  // rightFront.setPosition(Vector3(209, -109, -75));
  // rightRear.setPosition(Vector3(-209, -109, -75));

  // Standing wider
  // leftFront.setPosition(Vector3(243, 158, -75));
  // leftMiddle.setPosition(Vector3(0, 279, -75));
  // leftRear.setPosition(Vector3(-243, 158, -75));

  // rightFront.setPosition(Vector3(243, -158, -75));
  // rightMiddle.setPosition(Vector3(0, -279, -75));
  // rightRear.setPosition(Vector3(-243, -158, -75));  

  servoBus.syncWrite();    

  Serial << leftFront.computePositionFromAngles(0*deg2rad, 25.91*deg2rad, -4.98*deg2rad) << endl;
  Serial << leftMiddle.computePositionFromAngles(0*deg2rad, 25.91*deg2rad, -4.98*deg2rad) << endl;
  Serial << leftRear.computePositionFromAngles(0*deg2rad, 25.91*deg2rad, -4.98*deg2rad) << endl;

  Serial << rightFront.computePositionFromAngles(0*deg2rad, 100.12*deg2rad, 16.26*deg2rad) << endl;
  Serial << rightMiddle.computePositionFromAngles(0*deg2rad, 100.12*deg2rad, 16.26*deg2rad) << endl;
  Serial << rightRear.computePositionFromAngles(0*deg2rad, 100.12*deg2rad, 16.26*deg2rad) << endl;


  while (true)
  {
    // stay here, do not continue; uncomment for the test movement below
  }

  // Test simple leg movement
  for (int y=240; y<=280; y++)
  {
    leftFront.setPosition(Vector3(leftFront.getOffset().x, y, 0));
    leftMiddle.setPosition(Vector3(leftMiddle.getOffset().x, y, 0));
    leftRear.setPosition(Vector3(leftRear.getOffset().x, y, 0));

    rightFront.setPosition(Vector3(rightFront.getOffset().x, -y, 0));
    rightMiddle.setPosition(Vector3(rightMiddle.getOffset().x, -y, 0));
    rightRear.setPosition(Vector3(rightRear.getOffset().x, -y, 0));

    servoBus.syncWrite();    
    delay(20);
  }


  for (int x=0; x<=60; x++)
  {
    leftFront.setPosition(Vector3(leftFront.getOffset().x + x, 280, 0));
    leftMiddle.setPosition(Vector3(leftMiddle.getOffset().x + x, 280, 0));
    leftRear.setPosition(Vector3(leftRear.getOffset().x + x, 280, 0));

    rightFront.setPosition(Vector3(rightFront.getOffset().x + x, -280, 0));
    rightMiddle.setPosition(Vector3(rightMiddle.getOffset().x + x, -280, 0));
    rightRear.setPosition(Vector3(rightRear.getOffset().x + x, -280, 0));

    servoBus.syncWrite();    
    delay(20);
  }

  for (int x=60; x>=0; x--)
  {
    leftFront.setPosition(Vector3(leftFront.getOffset().x + x, 280, 0));
    leftMiddle.setPosition(Vector3(leftMiddle.getOffset().x + x, 280, 0));
    leftRear.setPosition(Vector3(leftRear.getOffset().x + x, 280, 0));

    rightFront.setPosition(Vector3(rightFront.getOffset().x + x, -280, 0));
    rightMiddle.setPosition(Vector3(rightMiddle.getOffset().x + x, -280, 0));
    rightRear.setPosition(Vector3(rightRear.getOffset().x + x, -280, 0));

    servoBus.syncWrite();    
    delay(20);
  }

  for (int y=280; y>=240; y--)
  {
    leftFront.setPosition(Vector3(leftFront.getOffset().x, y, 0));
    leftMiddle.setPosition(Vector3(leftMiddle.getOffset().x, y, 0));
    leftRear.setPosition(Vector3(leftRear.getOffset().x, y, 0));

    rightFront.setPosition(Vector3(rightFront.getOffset().x, -y, 0));
    rightMiddle.setPosition(Vector3(rightMiddle.getOffset().x, -y, 0));
    rightRear.setPosition(Vector3(rightRear.getOffset().x, -y, 0));

    servoBus.syncWrite();    
    delay(20);
  }
}

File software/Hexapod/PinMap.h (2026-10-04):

// Single source of truth for every GPIO used in the project
#pragma once

// I2S (audio)
constexpr int cI2S_DOUT = 13;  // I2S Data out pin
constexpr int cI2S_BCLK = 14;  // Bit clock
constexpr int cI2S_LRC  = 21;  // Left/Right clock, also known as Frame clock or word select

// I2C (display + IMU)
constexpr int cI2C_SDA  = 8;
constexpr int cI2C_SCL  = 9;

// NeoPixels (WS2812B)
constexpr int cLedDataPin = 11; 

// Dynamixel
constexpr int cDXLDirPin = 16; 
constexpr int cDXL_RX    = 18; 
constexpr int cDXL_TX    = 17;

// Misc
constexpr int cOnOffSwitchPin = 48;
constexpr int cUSBSensePin    = 10;

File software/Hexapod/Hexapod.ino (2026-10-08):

// ---------------------------------------------------------------------------------------------
// Hexapod — This application implements the control logic for a hexapod robot with 18 servos.
//           It receives motion and control commands from a remote controller via ESP-NOW
//           and translates them into coordinated leg movements.
//
//           Christoph Streit - 2026
// ---------------------------------------------------------------------------------------------

#include <Streaming.h>
#include <esp_system.h>   // esp_reset_reason()
#include <esp_core_dump.h> // esp_core_dump_get_summary()
#include <iterator>        // std::size
#include "PinMap.h"
#include "Receiver.h"
#include "Hexapod.h"

Receiver receiver;
Hexapod hexapod(receiver);

// ---------------------------------------------------------------------------------------------
static const char* resetReasonName(esp_reset_reason_t reason)
{
  switch (reason)
  {
    case ESP_RST_POWERON:   return "power-on";
    case ESP_RST_EXT:       return "external reset pin";
    case ESP_RST_SW:        return "software restart";
    case ESP_RST_PANIC:     return "panic / exception";
    case ESP_RST_INT_WDT:   return "interrupt watchdog";
    case ESP_RST_TASK_WDT:  return "task watchdog";
    case ESP_RST_WDT:       return "other watchdog";
    case ESP_RST_DEEPSLEEP: return "deep-sleep wake";
    case ESP_RST_BROWNOUT:  return "brownout - supply voltage dipped";
    case ESP_RST_SDIO:      return "SDIO";
    default:                return "unknown";
  }
}

// ---------------------------------------------------------------------------------------------
// A panic (including a task watchdog timeout) saves a core dump to the coredump partition. This
// prints its summary: the task that crashed, its program counter and backtrace. Decode the
// addresses against the .elf of the same build, e.g. with the ESP Exception Decoder or
//   xtensa-esp32s3-elf-addr2line -pfiaC -e Hexapod.ino.elf <address> ...
// The dump stays in flash until the next panic overwrites it, so it is erased once it has been
// printed to an open serial monitor; otherwise it would be reported again at every boot.
static void reportCoreDump()
{
  if (esp_core_dump_image_check() != ESP_OK)
    return; // no dump stored, or a corrupted one

  esp_core_dump_summary_t summary;
  if (esp_core_dump_get_summary(&summary) != ESP_OK)
    return;

  Serial << "Core dump from an earlier crash: task " << summary.exc_task
         << ", PC 0x" << _HEX(summary.exc_pc) << endl;

  Serial << "  Backtrace:";
  for (uint32_t i = 0; i < summary.exc_bt_info.depth && i < std::size(summary.exc_bt_info.bt); i++)
    Serial << " 0x" << _HEX(summary.exc_bt_info.bt[i]);
  Serial << (summary.exc_bt_info.corrupted ? " (corrupted)" : "") << endl;

  if (Serial)
    esp_core_dump_image_erase();
}

// ---------------------------------------------------------------------------------------------
void setup()
{
  // Read the USB sense pin before anything else: it tells us whether a host is attached,
  // which decides both how long we wait for the serial port and how much we log.
  pinMode(cUSBSensePin, INPUT);
  const bool usbConnected = (digitalRead(cUSBSensePin) == HIGH);

  Serial.begin(115200);

  // Allow a maximum of 1 second for a USB connection, otherwise boot anyway.
  // Only worth waiting at all if a host is actually there.
  if (usbConnected)
  {
    unsigned long startTime = millis();
    while (!Serial && (millis() - startTime < 1000))
      delay(10);
  }

  Serial << "\n\nSW version from " << __DATE__ << " " << __TIME__ << endl;
  Serial << (usbConnected ? "USB connected" : "USB not connected") << endl;

  // Why did the last run end? Anything other than a power-on or a deliberate reset means it ended
  // abnormally - a panic, a watchdog timeout, or the supply dipping. Unchecked, such a reboot is
  // indistinguishable from a normal start. The robot reads the pack voltage while it runs, but
  // that log is gone after a reboot, so ESP_RST_BROWNOUT is the evidence that a run ended because
  // the pack gave out rather than because of a firmware fault. Logged here, before anything else
  // can report an error of its own.
  const esp_reset_reason_t resetReason = esp_reset_reason();
  const bool abnormalReset = (resetReason != ESP_RST_POWERON &&
                              resetReason != ESP_RST_EXT &&
                              resetReason != ESP_RST_SW);

  Serial << "Reset reason: " << resetReasonName(resetReason)
         << (abnormalReset ? "   *** previous run ended abnormally ***" : "") << endl;

  // Not only after an abnormal reset: a crash on battery is usually followed by a power-on
  // once the robot is back on the bench.
  reportCoreDump();

  // Verbose IDF logging only when a host is attached to receive it. Untethered there is
  // nobody reading, but the messages would still be formatted and pushed into the same
  // UART that the control loop shares - so keep it down to warnings.
  esp_log_level_set("*", usbConnected ? ESP_LOG_VERBOSE : ESP_LOG_WARN);

  Wire.begin(cI2C_SDA, cI2C_SCL); // better to explicitly set them

  if (receiver.begin(ESPNowConnection::cDefaultWifiChannel) == false)
  {
    // Continuing is harmless here: without a link, isLinkHealthy() never becomes true and the
    // control loop keeps the robot parked.
    Serial << "ERROR: " << __PRETTY_FUNCTION__ << " -> receiver.begin() failed" << endl;
  }

  const bool hexapodIsUp = hexapod.begin(abnormalReset);

  if (hexapodIsUp == false)
  {
    // Continuing is deliberate: it lets a test board without servos run the state machine, the
    // display and the LEDs. It is also safe - ServoBus refuses every move, torque and read until
    // all servos are configured, so the legs stay limp whatever state the robot reaches.
    Serial << "ERROR: " << __PRETTY_FUNCTION__ << " -> hexapod.begin() failed" << endl; 
  }
  else if (abnormalReset == true)
  {
    // Only when begin() succeeded: it raises its own fault on failure, and a dead servo bus
    // matters more than how the last run ended. Clears itself after 20 s.
    hexapod.statusDisplay().showError("ABNORMAL RESET", resetReasonName(resetReason));
  }

  Serial << "Setup complete. Starting ..." << endl;
}
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

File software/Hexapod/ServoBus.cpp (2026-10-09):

#include "ServoBus.h"
#include <VectorUtilities.h>
using namespace vectorutilities;
#include <Streaming.h>
#include <algorithm>   // std::clamp

using namespace ControlTableItem;

// ---- ServoBus --------------------------------------------------------------------------

#define DXL_SERIAL Serial1 

namespace
{

const float cDXLProtocolVersion = 2.0;
const unsigned long cBaud       = 3000000; 

// Goal PWM (item 100) is expressed in units of PWM Limit (item 36), which begin() pins to
// cPWMLimitRaw so this conversion is deterministic rather than depending on whatever the servo
// happens to hold. 885 is the XC430 maximum and its factory default.
const int32_t cPWMLimitRaw = 885;
const int16_t cMaxPWMRaw   = 885; // 100 %
const int16_t cSafePWMRaw  = 442; //  50 %

// Written to each servo's MIN_VOLTAGE_LIMIT, in the control table's unit of 0.1 V.
// 99 = 9.9 V = 3.3 V/cell on a 3S LiPo. Below it the servo flags an input voltage error, but that
// is an alert only: Shutdown (item 63) keeps its default, which leaves input voltage out, so the
// servo keeps running.
const int32_t cMinVoltageLimit = 99;

// Address and length of control table item "Goal Position"
const uint16_t cGoalPositionAddr = 116;
const uint16_t cGoalPositionLen  = 4;

// Address and length of control table item "Present Position"
const uint16_t cPresentPositionAddr = 132;
const uint16_t cPresentPositionLen  = 4;

// Address and length of control table item "Torque Enable"
const uint16_t cTorqueEnableAddr = 64;
const uint16_t cTorqueEnableLen  = 1;

// Address and length of control table item "Goal PWM"
const uint16_t cGoalPWMAddr = 100;
const uint16_t cGoalPWMLen  = 2;

// How often syncReadPresentPosition() tries before it gives up.
constexpr int cReadAttempts = 3;

} // namespace

// ----------------------------------------------------------------------------------------
ServoBus::ServoBus(int dirPin, int rxPin, int txPin)
: myDXL(DXL_SERIAL, dirPin),
  myRXPin(rxPin), myTXPin(txPin),
  myAllServosAreConfigured(false)
{}

// ----------------------------------------------------------------------------------------
bool ServoBus::begin()
{
  for (int i=0; i<cNumServos; i++)
  {
    if (myServos[i].isConfigured == false)
    {
      Serial << "ERROR: " << __PRETTY_FUNCTION__ << " -> not all servos are configured, found idx " << i << endl;
      return false;
    }
  }

  // Order matters here and is not a mistake. Dynamixel2Arduino::begin() calls begin(baud) on
  // the underlying HardwareSerial itself, which brings the port up on Serial1's *default*
  // pins. Re-opening it afterwards with explicit pin arguments is what actually binds the bus
  // to cDXL_RX/cDXL_TX. 
  myDXL.begin(cBaud);
  DXL_SERIAL.begin(cBaud, SERIAL_8N1, myRXPin, myTXPin);
  myDXL.setPortProtocolVersion(cDXLProtocolVersion);
  myDXL.torqueOff(DXL_BROADCAST_ID);

  // Check if all servos are responding to a ping request
  for (int i=0; i<cNumServos; i++)
  {
    if (myDXL.ping(myServos[i].id) == false)
    {
      Serial << "ERROR: " << __PRETTY_FUNCTION__ 
                          << " -> ping failed for servo " << myServos[i].id 
                          << " error code " << myDXL.getLastLibErrCode()
                          << endl;
      return false;
    }
  }

  // Configure various servo parameters. Every write is checked
  for (int i=0; i<cNumServos; i++)
  {
    myDXL.torqueOff(myServos[i].id); // required before changing operating mode

    bool ok = true;

    // ---- EEPROM items (control table address < 64). These persist across power cycles, so
    // they are only written when they differ - see writeEEPROMItemIfChanged().

    // OPERATING_MODE is EEPROM too, but go through the library's setOperatingMode() rather
    // than a raw register write, since that also validates the mode against the servo model.
    const int32_t mode = myDXL.readControlTableItem(OPERATING_MODE, myServos[i].id);
    if (myDXL.getLastLibErrCode() != DXL_LIB_OK || mode != OP_POSITION)
      ok &= myDXL.setOperatingMode(myServos[i].id, OP_POSITION);

    ok &= writeEEPROMItemIfChanged(RETURN_DELAY_TIME,  myServos[i].id, 10); // 10 * 2 us = 20 us, for faster syncReads
    ok &= writeEEPROMItemIfChanged(MIN_POSITION_LIMIT, myServos[i].id, myServos[i].minPos);
    ok &= writeEEPROMItemIfChanged(MAX_POSITION_LIMIT, myServos[i].id, myServos[i].maxPos);
    ok &= writeEEPROMItemIfChanged(MIN_VOLTAGE_LIMIT, myServos[i].id, cMinVoltageLimit);

    // Pin the PWM ceiling so the raw Goal PWM values used elsewhere mean a known percentage.
    ok &= writeEEPROMItemIfChanged(PWM_LIMIT, myServos[i].id, cPWMLimitRaw);

    // ---- RAM items: reset to defaults on every power-up, so these must be written each boot.
    ok &= myDXL.writeControlTableItem(PROFILE_ACCELERATION, myServos[i].id, 0); // infinite acceleration time ('0 [msec]')
    ok &= myDXL.writeControlTableItem(PROFILE_VELOCITY, myServos[i].id, 0);     // '0' represents an infinite velocity (max speed)

    ok &= myDXL.writeControlTableItem(POSITION_P_GAIN, myServos[i].id, myServos[i].positionPGain); // see cDefaultPositionPGain
    ok &= myDXL.writeControlTableItem(POSITION_I_GAIN, myServos[i].id, 0);   // default 0
    ok &= myDXL.writeControlTableItem(POSITION_D_GAIN, myServos[i].id, 0);   // default 0

    ok &= myDXL.writeControlTableItem(GOAL_PWM, myServos[i].id, cSafePWMRaw);

    if (ok == false)
    {
      Serial << "ERROR: " << __PRETTY_FUNCTION__ 
             << " -> failed to configure servo " << myServos[i].id << endl;
      return false;
    }

    myDXL.ledOff(myServos[i].id);

    // Deliberately no torqueOn() here - see the class-level comment in ServoBus.h for
    // why. Torque is enabled later by the caller, only after it has pushed a goal
    // position matching the servo's actual current position.
  }

  // Fill the members of the structure to syncWrite using internal packet buffer
  mySyncWriteInfos.packet.p_buf        = nullptr;
  mySyncWriteInfos.packet.is_completed = false;
  mySyncWriteInfos.addr                = cGoalPositionAddr;
  mySyncWriteInfos.addr_length         = cGoalPositionLen;
  mySyncWriteInfos.p_xels              = mySyncWriteXels;
  mySyncWriteInfos.xel_count           = cNumServos;

  for (int i = 0; i < cNumServos; i++)
  {
    mySyncWriteXels[i].id     = myServos[i].id;
    mySyncWriteXels[i].p_data = (uint8_t*)&mySyncWriteData[i].goal_position;
  } 

  // Fill the members of the structure to fastSyncRead using internal user packet buffer
  mySyncReadInfos.packet.p_buf        = nullptr;
  mySyncReadInfos.packet.is_completed = false;
  mySyncReadInfos.addr                = cPresentPositionAddr;
  mySyncReadInfos.addr_length         = cPresentPositionLen;
  mySyncReadInfos.p_xels              = mySyncReadXels;
  mySyncReadInfos.xel_count           = cNumServos;  

  for (int i = 0; i < cNumServos; i++)
  {
    mySyncReadXels[i].id = myServos[i].id;
    mySyncReadXels[i].p_recv_buf = (uint8_t*)&mySyncReadData[i];
  }
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

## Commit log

2026-08-08 Update README with PCB images and test harness details
    Added images and test harness information to README.
2026-08-08 PCB images added
2026-08-08 1-joy transmitter use LZ to turn (yaw)
    RX (-> 2-joy transmitter) or LZ (1-joy transmitter) rotate hexapod around its vertical axis (yaw)
2026-08-21 Update offset and leg parameters
2026-08-21 Added rotation to coxa, femur and tibia joints
    [Hexapod.f3z]
2026-08-21 Add hexapod CAD image to README
    Add image link for hexapod CAD in README
2026-10-04 Update leg geometry
2026-10-04 Fix spelling, grammar and outdated comments
    [GaitEngine.h, Gaits.cpp, Gaits.h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]
2026-10-04 Update to esp32 core 3.3.12 and Dynamixel2Arduino 0.8.2
2026-10-04 Enable extra compiler warnings and fix all warnings in own code
    [Hexapod.cpp, IndicatorLeds.h]
2026-10-05 Explain why the state machine continues after a failed servo init
    [Hexapod.cpp, Hexapod.ino]
2026-10-06 Correct the scheduler task's watchdog comment
    [Hexapod.cpp]
2026-10-06 Keep the transmitter type in the Receiver and turn with LZ on a 1-joystick transmitter
    - Receiver stores the transmitter type at pairing; GaitEngine no longer copies the peer record every tick
    - GaitEngine's no-gait warning flag is a member, not a function-local static
    - Receiver::turnAxis() picks LZ or RX; used for yaw, the commanded test, LEDs and gaze
    [GaitEngine.h, Hexapod.cpp]
2026-10-07 Calibrate the IMU at its rated bus clock
2026-10-07 Disable the IMU and levelling when the IMU does not answer at boot
2026-10-07 Store the IMU's level reference and recalibrate it from the transmitter
    - Accelerometer offsets are stored in NVS and recalibrated with "Level IMU" (right button) in eReady
    - Gyro offsets are still calibrated at every boot; only stillness is needed for them
2026-10-07 Document Level IMU, the stored level reference and the IMU fault
2026-10-07 Run the control loop at a fixed rate and report overruns
    [Hexapod.cpp, Hexapod.h, Hexapod.ino]
2026-10-07 Update the bench sketches to the current board and fix their ID range and torque order
    [DefaultPosition.ino, IKMath.ino, Leg.cpp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]
2026-10-07 Read the control-data timestamp before millis(), and tidy constructors and casts
2026-10-07 Round servo goals instead of truncating, and correct the display rate comment
    [Hexapod.cpp, ServoBus.h]
2026-10-07 Print the core dump summary at boot after a crash
    [Hexapod.ino]
2026-10-07 Document that one set of joint limits covers all legs
2026-10-07 Note that LevelGait's filter constant is per control tick
2026-10-08 LevelGait: integrate the measured tilt instead of using it as the correction
    [Gaits.cpp, Gaits.h]
2026-10-08 Never switch torque on against positions that could not be read
    - ServoBus retries the position read and refuses torque-on from off until a read has succeeded since torque went off; refusals are logged and shown as SERVO READ FAILED
    - ParkGait starts from the current goals when torque is on, as StandUpGait already did
    [Gaits.cpp, Hexapod.cpp, Hexapod.h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]
2026-10-08 Pause a leg instead of jerking it when a foot target is too close to reach
    [GaitEngine.h, Leg.cpp]
2026-10-08 ServoBus: raise the position P gain to the default 700
2026-10-08 Set the servo P gain per joint: coxa 700, femur and tibia 400
2026-10-08 Warn when the battery runs low
2026-10-09 Show a failed servo read on the display even with torque on
    [Hexapod.cpp, ServoBus.cpp, ServoBus.h]
2026-10-10 Send the heartbeat every 200 ms so a lost frame no longer parks the robot
2026-10-30 Add print profiles for the coxa, tibia and top plate
2026-10-30 profiles cover the parts that need supports; material advice
2026-10-30 Revert "profiles cover the parts that need supports; material advice"
    This reverts commit 4d22a1a9f1e82dbabdddb980d713eead6218aebd.
2026-10-30 Add StatusDisplay3DTest: 3D eyes, sleepy mood, new happy arc
    A hardware test sketch with an extended copy of StatusDisplay. The firmware
    is unchanged and does not use it yet.
    - Perspective: the flat eyes are wrapped onto a round shell that turns with
    the gaze. With the gaze centred they look exactly like the current eyes.
    Toggle with 'd' to compare.
    - Mood::eSleepy: one half-closed lid and one thin, drooping slit that swap
    sides about every 7 s, nodding off about every 10 s. No blinking.
    - Happy: a tapered arc with round ends, drawn in place of the eye. It
    blinks by squashing flat instead of closing like a box.
    - The sketch steps through gaze sweeps and every mood, and logs the
    sl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
2026-10-30 StatusDisplay: 3D eyes and a new happy arc
    The eyes now sit on a round shell that turns with the gaze: looking aside,
    the near eye grows and the far one narrows and tapers, instead of both
    sliding across the screen. Each eye is still drawn as a clean shape, so the
    front view is unchanged, and it costs about 0.1 ms a frame. Tested in
    HWTests/StatusDisplay3DTest.
